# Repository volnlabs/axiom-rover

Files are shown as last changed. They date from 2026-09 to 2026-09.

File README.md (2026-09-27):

# Axiom Rover

**Interactive 3D inspection:** [open the hosted viewer](https://axiom-rover.vercel.app/) or [inspect the PCB](https://axiom-rover.vercel.app/?mode=pcb) — rotate, zoom, inspect all sides, hide the shell, or separate parts. [Local viewing and deployment instructions](viewer/README.md).

After cloning, use [the Git LFS checkout instructions](docs/build.md) to download the full assembly STEP, Pi reference STEP and viewer mesh before opening or rebuilding them.

A reusable 2WD release-test robot: one fixed Shrike/RP2040 + ForgeFPGA actuator base, a removable compute tray, an independent motor-power stop, and a wheels-raised stand. This is an **independent hardware repository**, not part of the AxiomOS source tree.

**Revision B is a design-review prototype, not released for fabrication or powered motion.** The carrier now has a bottom Pi 5 socket, two top Shrike R0.4 sockets, an onboard DRV8833 motor driver, and HC-SR04, wheel-encoder and IMU connectors. Vendor CAD and nominal socket models establish design coordinates; physical fit and powered tests remain outstanding.

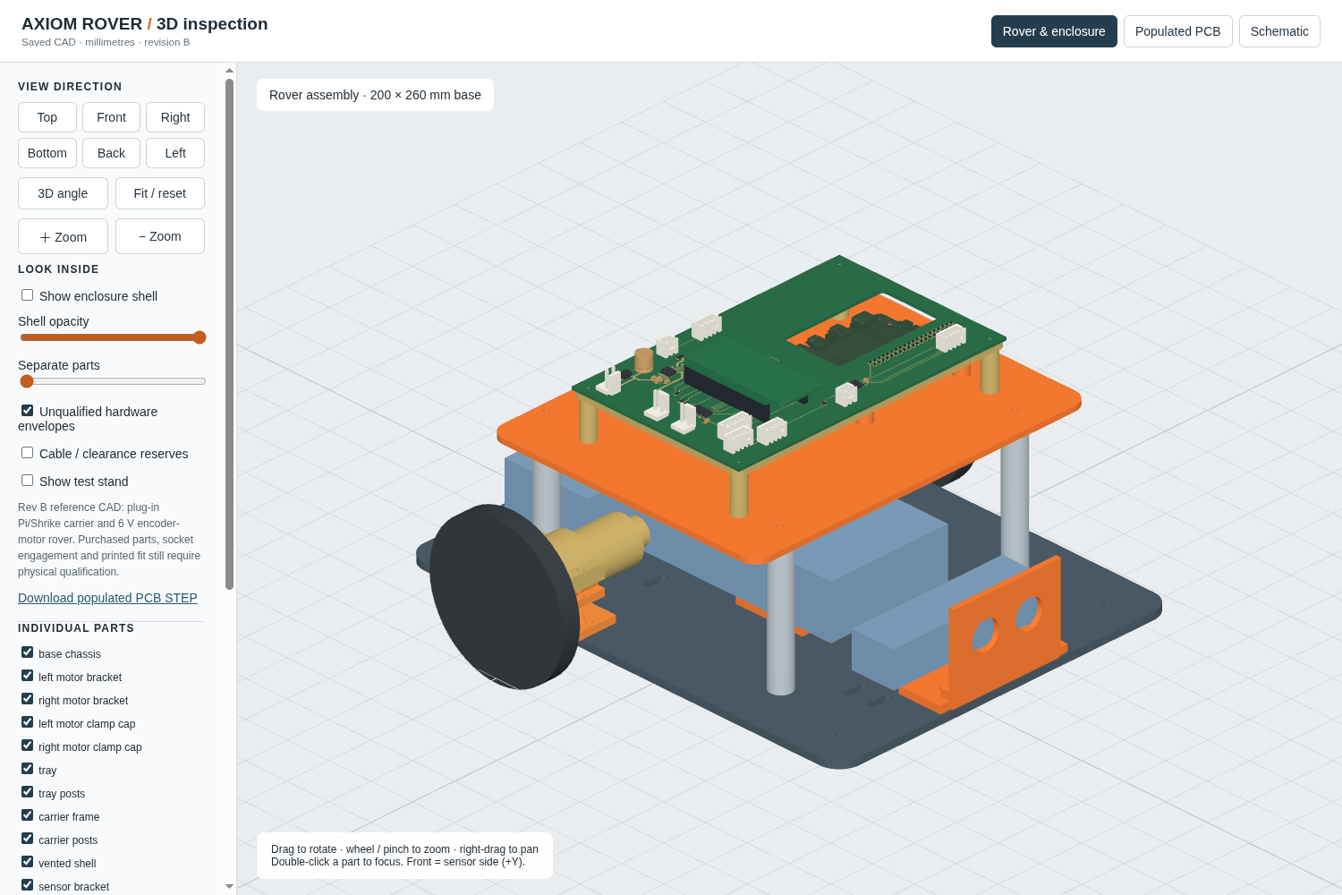
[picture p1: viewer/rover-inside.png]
Populated carrier and enclosure interior


- [Editable KiCad project](electronics/carrier.kicad_pro), [schematic](electronics/carrier.kicad_sch), [routed PCB](electronics/carrier.kicad_pcb), and [schematic drawing](electronics/out/schematic/carrier.svg).
- [Parametric mechanical source](mechanical/axiom_rover.py), [STEP assembly](mechanical/out/axiom_rover_assembly.step), and individual STL parts in [mechanical/out](mechanical/out/).
- [Electrical and harness contract](docs/electrical-contract.md), [wiring diagram](docs/harness.svg), [mechanical interfaces](docs/mechanical.md), [system BOM](bom/system-bom.csv).
- [Assembly, procurement and commissioning](docs/commissioning.md), [post-v1.0 compute roadmap](docs/compute-roadmap.md), [reproduction instructions](docs/build.md).
- [Controller bench fixture and motor-disconnected test procedure](docs/bench.md).
- [Native electrical check results](electronics/out/drc.json), [mechanical checks](mechanical/out/mechanical_checks.json), [populated assembly checks](mechanical/out/assembly-fit.json), [42 browser checks](viewer/browser-check.json), and [release gates](release-gates.json).

The carrier is 160 × 100 × 1.6 mm, two layers, with a cooler aperture. The Pi sits below it at a 16.5 mm gap and Shrike plugs into two 19-position sockets above. Two 6 V ThinkRobotics MOT3001-6V60RPM encoder motors drive 80 mm Pololu 3690 wheels. DRV8833 current regulation targets 1 A per channel; actual current and thermal behavior require bench measurements. The external fuse, normally-open motor-power relay, regulated motor source and separate host/base supplies remain off-board. Power down before compute swaps; J1 and alternate-host J12 cannot be used together.

A robot supplies repeatable evidence for named releases and fault cases. It cannot prove AxiomOS correct under every possible condition. Every physical result must identify the software/FPGA hashes, hardware revision, power state and raw capture.

Budget cap: ₹30,000 excluding compute boards and instruments, with ₹6,000 reserved for a revision. The current estimate is ₹20,821.98–₹45,459.98 before reserve (₹26,821.98–₹51,459.98 including it), not a vendor quote. First-order quotes must total at most ₹24,000 before ordering. Nothing has been purchased, fabricated, flashed or physically tested here.

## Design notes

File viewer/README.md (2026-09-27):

# Interactive Rev B.1 CAD inspection

Hosted on Vercel: [rover and enclosure](https://axiom-rover.vercel.app/),
[PCB](https://axiom-rover.vercel.app/?mode=pcb),
[schematic](https://axiom-rover.vercel.app/?mode=schematic).

Start `python3 -m http.server 8765 --bind 127.0.0.1` in the repository root.
Open [the rover](http://127.0.0.1:8765/viewer/) or
[the PCB](http://127.0.0.1:8765/viewer/?mode=pcb).

Drag to rotate, wheel/pinch to zoom, right-drag to pan, or select any of six
sides. Double-click a component to focus it. Hide or fade the enclosure,
separate the assembly, or hide individual components. Copper and schematic
views support zoom and pan. The same viewer works locally and as a static Vercel deployment.

The 160×100 mm Rev B.1 PCB includes a bottom Pi socket, two top Shrike sockets,
onboard DRV8833 and the sensor/encoder/IMU connectors. Geometry comes from
the actual saved PCB and STEP assemblies. Component meshes are grouped by
reference designator, including the individual socket contacts.

The Pi uses official source CAD. The Shrike model derives its outline and
hole positions from the R0.4 PCB; its male header plastic/pins are nominal,
and its component population is not fully modeled. The original Shrike STEP
has a documented header-position mismatch and is excluded from the assembly.
Samtec socket bodies and JST VH plastic are nominal drawing-based models;
other packages use KiCad library references. Motors/wheels use supplier
dimensions. Packs, caster and fit tolerances remain unmeasured envelopes.
This is a review assembly, not a physical fit or fabrication release.

Use [docs/build.md](../docs/build.md) to regenerate CAD, attach local models,
export populated STEP and refresh `meshes.json`. Provenance is in
`model-sources.json` and `../reference/`; hashes reject stale geometry.

[The browser self-test](http://127.0.0.1:8765/viewer/?test=1) checks required
components, the plugged module, every viewing direction, zoom, enclosure
visibility, exploded view, component hiding and schematic switching.
WebGL2 is required.

Three.js 0.180.0 / OrbitControls are vendored under MIT (`vendor/LICENSE`).
KiCad models retain their library license; see [THIRD_PARTY.md](../THIRD_PARTY.md).

## Vercel hosting

From the repository root, build and check the upload bundle:

```sh
python3 tools/build-viewer-site.py
python3 tools/check-viewer-site.py
node tools/check-viewer-ui.mjs
python3 tools/check-viewer.py --site-root .vercel/output/static --report-dir .cache/viewer-site-check
npx --yes vercel@59.15.0 link --yes --project axiom-rover --scope utkarshs-projects-88519d03
npx --yes vercel@59.15.0 deploy --prebuilt --prod --yes
```

The builder emits Vercel's [static Build Output API](https://vercel.com/docs/build-output-api)
under ignored `.vercel/output/`. Its fixed allowlist contains the viewer and project
pages, the CAD and circuit downloads linked from them, provenance, and licenses.
It rejects missing files and Git LFS pointers before replacing the output; run
`git lfs pull` if the geometry is still a pointer. Only files listed in the
builder reach the public site. `.vercel/project.json` is local account/project
configuration and stays ignored. Deploy the prebuilt output; a source deployment
from the repository root would upload unrelated CAD.

The output configuration serves `/viewer/` explicitly and applies a same-origin
content policy, basic security headers, and revalidation caching. Revalidation
matters because the asset URLs do not contain content hashes. The inline import
map is allowed by a hash generated from the source HTML during packaging.
The UI check uses Node.js 22+ and `chromium` on `PATH`; it runs against the
packaged site and writes browser reports under `.cache/viewer-ui/`.

The geometry is compressed losslessly from about 100 MB to 17 MB; the complete
bundle is about 40 MB. The hosted entry point uses the browser's native
[DecompressionStream](https://developer.mozilla.org/en-US/docs/Web/API/DecompressionStream).
A current browser with WebGL2 is required. Local viewing still loads the original
`meshes.json`. Both `/` and `/viewer/` support the existing `?mode=pcb`,
`?mode=schematic`, `?view=bottom`, and `?shell=0` links.

After deploying, check the public URL with the same browser test:

```sh
python3 tools/check-viewer.py --site-root .vercel/output/static \
  --report-dir .cache/vercel-live-check --url 'https://axiom-rover.vercel.app/'
```

The source hashes in that report describe the local bundle; verify downloaded
asset hashes separately when tying a remote deployment to this checkout. Hosting
does not change fabrication or physical-test release status.

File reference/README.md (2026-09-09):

# Vendor reference files

Retrieved 2026-09-09. These are vendor design/reference data, not measurements of the user's hardware. Source hashes are in `sources.json`.

- `shrike-r04/Shrike-lite.kicad_pcb` and `Shrike-lite.step`: unmodified Vicharak files from commit `763d0a7dd9ebdfc3f61de148457d5c34f112f61e`, `hardware/shrike-lite/kicad/v1_r0.4`. Hardware license: included `shrike-r04/LICENSE_HW.md` (CERN OHL v1.2).
- `raspberry-pi-5/*.pdf`: unmodified Raspberry Pi Ltd mechanical drawings, with their original reference-only notes. These have not been re-licensed by this project.

The Shrike R0.4 PCB outline is approximately **25.4×58.5 mm**, corner radius 2 mm. Board-coordinate bounds are approximately X=135.801105…161.201095, Y=75.7536…134.2536 mm. Socket rows J2/J4 have **19 positions each**, **2.54 mm pitch**, and **22.86 mm row separation**. J2 pin 1 is at (137.071095,86.8494); J4 pin 1 at (159.931095,86.8746). Pin numbers increase toward increasing PCB Y. The published rows have a small **0.0252 mm longitudinal offset**; retain source coordinates and assess connector tolerance instead of silently assuming perfect alignment. USB-C is at the low-Y end. Header drill size on the vendor board is 0.9 mm; the carrier socket drill must follow the selected socket's drawing, not copy the module's drill blindly.

The Pi board is 85×56 mm. With the official drawing's lower-left outline as datum, its M2.5 mounting hole centres are (3.5,3.5), (61.5,3.5), (3.5,52.5), (61.5,52.5), with Ø2.7 holes. The hole grid centre is 10 mm left of the board centre. The Rev B model uses board centre (-37.5,2), with hole X positions -76.5/-18.5 and Y positions +26.5/-22.5 mm.

No source dimensions establish socket engagement, soldered header orientation, actual board revision or enclosure fit by themselves.

The Pi STEP archive RP-010083-CA and its extracted STEP retain Raspberry Pi's
included license. The GPIO and Samtec stack datums are recorded in
[connector-sources.md](raspberry-pi-5/connector-sources.md).

The original Shrike STEP header locations differ from the R0.4 PCB by about
9.46 mm longitudinally after matching the board outline and USB orientation.
It is retained as discrepant vendor reference data. The review assembly uses
PCB-derived Shrike geometry instead; it must not imply that the original STEP
proves socket mating. Header plastic/pin lengths remain nominal until measured.

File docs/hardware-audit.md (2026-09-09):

> Historical findings for Rev A at commit 57851dc. Rev B replaces the harness-only PCB with physical Pi/Shrike sockets and onboard motor drive; see [the implementation ledger](revb-plan.md) and current CAD. This document preserves the earlier audit, not the current interface.

# Historical Rev A hardware audit — 9 September 2026

**Revision A does not implement the requested plug-in Shrike carrier. Do not order it as the complete robot PCB.** It is a routed, low-current harness adapter. Fabrication, physical fit and powered-motion release gates remain false. No hardware was connected or tested in this audit.

## Findings and disposition

| Interface | Finding | Disposition |
|---|---|---|
| Shrike mounting | No socket footprint; J2 is a 16-pin IDC harness connector. The suggested interposer has no PCB design. | Replace this interface with two female 1×19 sockets on the fixed carrier. |
| Shrike geometry | Official R0.4 PCB and STEP files exist but were not used in the initial assembly. | Saved under `reference/shrike-r04`; derive the socket and module model from these files. |
| Pi 5 mounting | The 58×49 grid spacing was correct, but its position relative to the 85×56 board envelope was wrong by 10 mm in X. | Corrected the tray holes/bosses to the official drawing datum; regenerated CAD and viewer meshes. This is a CAD correction, not a physical fit test. |
| Pi 5 electrical | Carrier J1 had generic UART names without Pi physical pin numbers. There is no Pi 40-pin socket or top-board design. | Added the explicit four-wire mapping to the electrical contract. Runtime UART routing remains to be demonstrated. |
| HC-SR04 | Carrier J3 order differs from the sensor header; the bracket lacks a measured board-retention interface, and the assembly omits the sensor body. | Added the required harness permutation. Exact sensor fit and trigger acceptance remain unverified. |
| L298N | An unspecified module is represented together with Shrike by one 60×35×15 box. That is not evidence that either module, connectors or heatsink fit. | Use separate models and retention for the actual L298N and Shrike. Check module jumpers and terminal order. |
| Motors, wheels, caster, batteries, switch, relay, fasteners | Exact SKUs, mating features, cable paths and installation access are incomplete or unmeasured. | Do not treat collision-free boxes as a complete enclosure assembly. Select/measure parts and qualify retention and clearances. |
| Runtime and motor power | Shrike firmware explicitly remains safe-low/non-operational; FPGA timing/runtime integration and motor-current qualification are missing. | No claim of a working or safe moving rover. Follow commissioning gates before motion. |

The artifact checker passed on the original design despite the Pi datum error. It checked consistency of the modeled geometry, not correspondence with the real Pi. The corrected generator now checks bores and surrounding spacer material at coordinates independently taken from the vendor drawing.

Verification after correction: the CadQuery generator and artifact checker passed, with zero unexpected intersections among the modeled shapes. Reintroducing the old centred grid in memory failed the drawing-coordinate bore check (15.928 mm³ of obstructing material). The refreshed viewer matched both STEP source hashes and passed its 22 browser checks. These are file/CAD/browser checks; no physical test was run.

## Source-based electrical checks

Rechecked the official R0.4 **PCB pad net names**, not only our own schematic. The contract's used Shrike connections match: J2-2 = 3.3 V; J2-3 = GPIO5; J2-4…7 = GPIO6…9; J2-8 = GND; J2-9/10 = GPIO10/11; J2-16…18 = F_GPIO0…2; J4-17/18 = GPIO17/16. These match the intended UART, sensor, motor-direction and FPGA-enable nets. This does not verify the user's installed board revision, header soldering, FPGA pad binding or running firmware.

Rechecked TI's package-specific tables: ISO7721DR pins 1…8 are VCC1, OUTA, INB, GND1, GND2, OUTB, INA, VCC2; SN74LVC1G17DBVR pins 1…5 are NC, A, GND, Y, VCC. The carrier assignments agree. Neither result proves assembled orientation, power sequencing, isolation performance or sensor-clone compatibility. [ISO7721, figure 5-4/table 5-1](https://www.ti.com/lit/ds/symlink/iso7721.pdf); [SN74LVC1G17, pin table](https://www.ti.com/lit/ds/symlink/sn74lvc1g17.pdf).

## Corrected architecture recommendation

Keep a **physical Shrike socket on the fixed actuator carrier**, with the Pi on its removable upper tray. Use two female 1×19 socket strips, a board-outline/pin-1 marking, and a mechanical guide/retainer that prevents reversed or offset insertion. Select the actual socket/header pair and engagement height before finalizing its footprint. Preserve access to Shrike USB-C, boot/reset and debug connections. Keep the host/base power boundary and independent motor-power stop.

A Shrike socket on a **Pi 5 top add-on board** is also feasible, but it couples the actuator controller mechanically to the computer being swapped. It requires its own 40-pin mating connector, defined stack height, actual cooler/connector clearance and a new thermal/fit review. The official Active Cooler drawing gives 63.5×42.5×13.7 mm reference dimensions. A top board must allow fan intake/exhaust, plug access and installation space; the current enclosure proves none of those. Do not call it HAT/HAT+ compliant without checking the corresponding Raspberry Pi specification.

Before releasing either arrangement: import accurate separate board/component models; select all mating connectors and mounting hardware; check every pad against the vendor and every harness end against its device; rerun ERC/DRC, connectivity and actual-part mechanical checks; perform a paper/template socket fit and unpowered assembly; then follow current-limited electrical, partial-power, stop/watchdog and raised-wheel commissioning. Exact purchased dimensions and physical measurements remain required.

Sources: [pinned Vicharak R0.4 hardware](https://github.com/vicharak-in/shrike/tree/763d0a7dd9ebdfc3f61de148457d5c34f112f61e/hardware/shrike-lite/kicad/v1_r0.4), [Pi 5 mechanical drawing](https://datasheets.raspberrypi.com/rpi5/raspberry-pi-5-mechanical-drawing.pdf), [Active Cooler drawing](https://datasheets.raspberrypi.com/cooling/raspberry-pi-active-cooler-mechanical-drawing.pdf). Raspberry Pi labels its drawings approximate/reference-only and directs readers to physical hardware for complete component representation.

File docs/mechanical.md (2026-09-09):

# Axiom Rover mechanical Rev B

`mechanical/axiom_rover.py` is deterministic CadQuery 2.6 source. Run `/tmp/axiom-cad-tools/venv/bin/python mechanical/axiom_rover.py --output mechanical/out` to recreate the printable STLs, assembly STEP, `shrike-module.step`, overview and collision report.

The PETG lower deck is 200 × 260 × 4 mm. The 80 × 10 mm [Pololu 3690](https://www.pololu.com/product/3690) wheel references use the supplied 4 mm D collets and centres at `x=±120, y=-50, z=22.5`; the ground datum is `z=-17.5`. The four-pad test stand supports the base underside, clears both wheel references, and does not load motor axles. The shell wheel arches are enlarged for the 80 mm diameter and its upper rim reaches `z=141`. The native PCB-derived Shrike board top is about `z=121.324`; `z=135` remains the enclosure-clearance plane. The board-only export deliberately does not claim clearance for unmodeled Shrike components.

Each ThinkRobotics MOT3001-6V60RPM motor is a **vendor-dimension reference, not a measured fit**: 25 mm gearbox diameter × 23 mm long, 24.4 mm motor body × 31 mm, 9 mm encoder and 4 mm D shaft × 12 mm. The two split clamps use a 25.70 mm bore (0.35 mm radial print clearance), a 23.6 mm clamp length and a 1 mm split gap for closure. Each lower clamp foot is `24 × 52 mm` at the gearbox axis with two accessible M3 deck bolts at `y=axle±22`; it has two M3 clamp screws. The archived supplier drawing is [reference/motors/thinkrobotics25-dimensions.jpg](../reference/motors/thinkrobotics25-dimensions.jpg); validate purchased gearboxes, gearbox face/shaft position, print tolerance and clamp load before fabrication. The 80 mm wheels and their 4 mm collets are also vendor references; their published drawing specifies a 10.3 mm maximum width and about 6 mm collet/plate thickness, compatible with the 12 mm shaft on paper only.

The host pack reserve moved below the tray, centrally at `70 × 120 × 30 mm`, lower face `z=10`; it has four deck strap slots. The former front/rear motor-pack (`90 × 50 × 25`) and base-5V (`90 × 25 × 20`) reserves remain explicitly **unqualified**. Moving the host reserve exposed an encoder conflict at the previous wheel track; the 120 mm wheel centres give the encoder a 5 mm lateral clearance to that reserve. This has no physical-pack fit claim.

The Pi 5 drawing datum is PCB-local `(0,20)..(85,76)`, world centre `(-37.5,2)`, board bottom/top `z=89/90.6`. Its four drawing holes are world `(-76.5,26.5)`, `(-18.5,26.5)`, `(-76.5,-22.5)`, `(-18.5,-22.5)`. Power-off service is: unscrew and lift the carrier at least 7 mm to disengage GPIO; remove the carrier and perimeter frame; unbolt the Pi; lift it 2 mm; then slide it left through the `z=76..110` opening. `pi5_after_carrier_removal_service_SWEEP` is the conservative full official-Pi bounding volume for that final slide and is checked against the remaining printable parts. The official Pi STEP is included as a separate source-CAD reference. Its 85 × 56 × 1.276 substrate solid, not its full connector-inclusive bounds, is placed natively with source lower-left at world `(-80,-26)` and board lower face `z=89`; neither source CAD nor the Shrike CAD is mirrored.

The carrier uses the final 160 × 100 × 1.6 PCB contract: KiCad `(0,0)` is world `(-80,+50,z107.1)` and KiCad `+y` maps world `-y`. It is supported independently at PCB `(5,5)`, `(155,5)`, `(155,95)`, `(5,95)` by four dielectric posts down to the tray. Its frame is a 3 mm perimeter rim (`160 × 100` outside, `154 × 94` open inside) with 8 mm corner bosses and M3 holes, leaving the full PCB interior open for THT tails and the DRV thermal-pad back. The Pi drawing holes remain clearanced. The `60 × 34` **airflow window** at PCB `(8,32)..(68,66)` is therefore an airflow projection, not a component-through-fit claim: it clears the specified `60 × 34 × 13.7` projection only; the official cooler outline is `63.5 × 42.5`. The open interior also clears the downward Samtec ESQ-120-24-G-D reference body (`51.31 × 4.95 × 13.59`), placed from the official Pi header datum `pin1=(8.37,24.77)`, `pin2=(8.37,22.23)` in PCB-local coordinates. `carrier_tails_CLEARANCE_REFERENCE`, derived from J1–J13 drilled pads in `electronics/out/pad-geometry.json`, is checked clear of the rim and bosses. The Pi PCB-top-to-carrier-underside gap is 16.5 mm; the stated 5.63 mm electrical engagement remains an electronics/mechanical stack assumption, not a measured assembled result.

Shrike sockets are separate reference geometry: each SSW row is `48.77 × 2.41 × 8.51` above the carrier PCB, using the supplied row pin-1 coordinates `(100.27,21.0958)` and `(123.13,21.1210)`. Their top is `z=117.21`; the Shrike PCB lower face is modeled at `z=119.75`, with a nominal `2.54 × 48.26 × 2.54` male-header plastic section below it and 38 nominal `0.64` square, 6 mm pins below that. Plastic and pins are explicitly unmeasured. `shrike_pcbCAD_REFERENCE` imports the native KiCad board-only STEP export, including its actual outline, rounded corners and pads. `mechanical/out/shrike-module.step` combines that native board with the nominal plastic and all 38 pins, normalized to the J2 pin-1 contract origin with board lower face `z=0`; this is the model for KiCad/viewer attachment. The optional `shrike_component_UNMEASURED_ENVELOPE` covers the full bay from its board bottom through `+8 mm`; `shrike_usb_wire_UNMEASURED_ENVELOPE` reserves low PCB-Y/world `+Y` for a USB plug and wire. They are visible clearance references only and do not claim measured component fit. The vendor `Shrike-lite.step` remains report-only: a proper 180° Z rotation (never a mirror) can align its nominal `25.45 × 58.55008 × 1.51` substrate to the bay, but independent circular-hole extraction finds both source rows offset about `(+0.025,+9.462) mm` from the carrier contract. It is excluded from the assembly so it cannot imply a false mating fit.

`mechanical_checks.json` labels printable parts, vendor references, contract references and unqualified envelopes separately. It performs exact intersections for printable/reference geometry, allows wheel–shaft and intended Shrike pin–socket engagement, checks the airflow aperture and Pi service sweep, and records the vendor-STEP mismatch separately. Passing CAD checks do not validate print strength, motor fit, wheel retention, pack fit, thermal behavior, loading, speed, payload or physical tests.

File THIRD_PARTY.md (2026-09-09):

# Third-party design sources

`electronics/Rover.pretty/*.kicad_mod` are copies of the KiCad footprint library shipped with KiCad 10.0.6, except `Pi5_Socket_2x20` and `SSW-119-01-G-S`, which are original local footprints derived from the cited Samtec dimensions and Pi STEP datum. Original library families are recorded by `electronics/generate.py` and `electronics/out/assembly-bom.csv`; Standard-library pad shapes have not been redrawn; local model paths are updated. The upstream KiCad Libraries license is [CC BY-SA 4.0 with the KiCad design exception](electronics/Rover.pretty/LICENSE.md). Attribution: [KiCad Libraries contributors](https://gitlab.com/kicad/libraries/kicad-footprints). See the included license for the design exception and conditions on library redistribution.

Shrike pin assignments are derived from the pinned official Vicharak schematic; source URLs and SHA-256 values are in `docs/electrical-contract.md`. The pinned vendor PCB and STEP files are retained under `reference/`. U1/U2 assignments use Texas Instruments datasheets linked there. Raspberry Pi's mechanical drawing is linked in `docs/mechanical.md`. Their product names remain their owners' names; this is an independent reference prototype.

Unmodified official Shrike R0.4 PCB/STEP files and their CERN OHL v1.2 license, and unmodified Raspberry Pi Ltd reference mechanical PDFs, are retained in `reference/`. See its README and `sources.json` for provenance and hashes. The Raspberry Pi drawings retain their original notices and are not covered by the Shrike license.

KiCad, Freerouting and CadQuery are external tools, not project dependencies vendored into Git. The ignored `.cache/` directory may contain locally downloaded tooling. No repository-wide public license is chosen on the user's behalf; retain third-party attribution if the project is later published.

`electronics/models/` includes KiCad library package STEP references, attributed
in `viewer/model-sources.json`. Most carry CC BY-SA 4.0 with the KiCad design
exception. `D_SMB.step` and `CP_Radial_D8.0mm_P3.50mm.step` instead carry
GPLv3-or-later with the design exception embedded in their headers. Original
model notices and GPLv3 are retained in [viewer/model-licenses.txt](viewer/model-licenses.txt).
Samtec
socket bodies and the simplified JST VH body are original nominal geometry
created by `viewer/export_meshes.py` from cited manufacturer dimensions; they
are not manufacturer-certified STEP assemblies. The DRV8833 uses KiCad's
TSSOP-16-1EP 4.4×5 mm / EP3.4×5 mm reference model for the matching package
body; its exact PWP land pattern remains the separate PCB footprint.

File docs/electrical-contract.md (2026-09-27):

# Axiom rover electrical contract — Rev B.1 review

This is the accepted **160 x 100 mm Pi 5 carrier** contract. It records a design
under review, not a fabricated board, qualified harness, motion release, or
firmware implementation.

## Fixed boundaries

- Pi 5 is below the carrier. `J1` is `ESQ-120-24-G-D`, bottom-mounted, with a
  nominal carrier-underside-to-Pi-PCB gap of **16.5 mm**.
- Shrike R0.4 mates through `J2` and `J4`, each `SSW-119-01-G-S` 1 x 19
  socket. Delivered-header orientation and continuity remain physical checks.
- Shrike USB-C is its **only** 5 V input. Pi 5 V pins 2 and 4 and Shrike J2/J4 pin 1 (`VUSB`) are NC.
  `BASE_5V` is a separately supplied sensor rail only.
- The external 6 V motor rail reaches J7 only after an independent, rated stop
  relay and fuse. The PCB does not rate or replace either device.
- U1 isolates `H_GND` and `BASE_GND`; no carrier copper intentionally joins them.
- Rev B.1 retains the 160 x 100 mm outline, mounting holes, cooler aperture,
  connector positions and pinouts. Check the generated board against these
  fixed interfaces before fabrication.

## Pi socket and Shrike connector map

`J1` uses Pi physical-header numbering. All pins not listed are NC.

| J1 / Pi pin | Carrier net | Use |
|---:|---|---|
| 1, 17 | `HOST_3V3` | Pi 3.3 V for U1 host side |
| 6, 9, 14, 20, 25, 30, 34, 39 | `H_GND` | Pi ground for U1 host side |
| 8 | `H_TX` | Pi UART TX |
| 10 | `H_RX` | Pi UART RX |
| 2, 4 | NC | Pi 5 V; never power Shrike/carrier from Pi 5 V |

| J2 pin | Net | Shrike function / destination |
|---:|---|---|
| 1 | NC | — |
| 2 | `BASE_3V3` | Shrike 3.3 V |
| 3 | `ESTOP_RP` | RP GPIO5 observe |
| 4, 5 | `L_IN1`, `L_IN2` | left direction inputs |
| 6, 7 | `R_IN3`, `R_IN4` | right direction inputs |
| 8, 13 | `BASE_GND` | base return |
| 9, 10 | `US_TRIG`, `US_ECHO_3V` | HC-SR04 trigger / protected echo |
| 11, 12, 14, 15 | NC | — |
| 16 | `ESTOP_FPGA` | FPGA stop input |
| 17, 18 | `FPGA_PWM_L`, `FPGA_PWM_R` | FPGA PWM gates |
| 19 | `FAULT_FPGA_N` | FPGA `F_GPIO7` fault observe |

| J4 pin | Net | Shrike function / destination |
|---:|---|---|
| 1 | NC | — |
| 2 | `BASE_3V3` | Shrike 3.3 V |
| 3 | `IMU_INT` | IMU interrupt |
| 4 | `FAULT_RP_N` | RP GPIO28 fault observe |
| 5, 6 | `IMU_SCL`, `IMU_SDA` | I2C clock / data |
| 7, 13, 19 | `BASE_GND` | base return |
| 8, 9, 15, 16 | NC | — |
| 10, 11 | `ENC_R_B`, `ENC_R_A` | right encoder B / A |
| 12, 14 | `ENC_L_B`, `ENC_L_A` | left encoder B / A |
| 17, 18 | `RP_UART_RX`, `RP_UART_TX` | isolated UART RX / TX |

U5 (`SN74LVC125ADR`) gives each controller a separate one-way stop and fault
observation channel. Its four active-low enables are grounded; R16–R19 are
1 kΩ output resistors. J2-19/F_GPIO7 receives `FAULT_FPGA_N`; J4-4/GPIO28
receives `FAULT_RP_N`. Neither receiver can drive the source `DRV_FAULT_N`,
the hardwired `ESTOP_N`/nSLEEP net, or the other controller's observation
channel. Verify buffer propagation and the delivered Shrike pin labels.

## Carrier connectors and peripherals

| Ref | Family / purpose | Pin order, as generated |
|---|---|---|
| J3 | JST XH 1x4, HC-SR04 | `BASE_5V`, `SENSOR_TRIG`, `US_ECHO_5V`, `BASE_GND` |
| J5 | JST XH 1x2, logic NC stop loop | `BASE_3V3`, `ESTOP_N` |
| J6 | JST XH 1x2, sensor 5 V input | `BASE_5V`, `BASE_GND` |
| J7 | JST VH B2P-VH, post-fuse/stop 6 V | `MOTOR_6V`, `BASE_GND` |
| J8 | JST VH B2P-VH, left motor | `MOTOR_L_P`, `MOTOR_L_N` |
| J9 | JST VH B2P-VH, right motor | `MOTOR_R_P`, `MOTOR_R_N` |
| J10 | JST XH 1x4, left encoder | `BASE_GND`, `BASE_3V3`, `ENC_L_A`, `ENC_L_B` |
| J11 | JST XH 1x4, right encoder | `BASE_GND`, `BASE_3V3`, `ENC_R_A`, `ENC_R_B` |
| J12 | JST XH 1x4, alternate host UART | `HOST_3V3`, `H_GND`, `H_TX`, `H_RX` |
| J13 | JST XH 1x5, IMU | `BASE_GND`, `BASE_3V3`, `IMU_SDA`, `IMU_SCL`, `IMU_INT` |

The HC-SR04 uses 5 V. R1 (1 kΩ), R2 (2.2 kΩ), R3 (3.3 kΩ), and U2
`SN74LVC1G17DBVR` drive and protect its 3.3 V interface. R14/R15 are 4.7 kΩ
I2C pull-ups. Actual HC-SR04 header order and trigger threshold need bench
verification.

Encoder connector order is fixed above, but actual motor wire-end order,
polarity, phase, and quadrature CPR are unknown. Establish them by continuity
and a low-energy direction/phase test.

## Motor drive and stop behavior

U3 is `DRV8833PWPR`. R7/R8 are Stackpole `CSRT1206FTR200`, 0.20 Ω, 1 %, 1 W current-sense parts. The
design intent is **1 A nominal per motor channel**, contingent on current,
thermal, supply-sag, and driver-fault measurements.
For Rev B.1, place R7/R8 beside U3 with each sense trace at most 7 mm;
limit U3-to-capacitor pad-centre routed lengths to 4 mm for VM/VINT and
3 mm for VCP.
Retain 12 exposed-pad thermal vias, ground isolation and 0.8 mm motor trunks.
These are layout targets to verify in the regenerated board, not measured
electrical or thermal performance.

| Direction source | PWM gate | DRV8833 input |
|---|---|---|
| `L_IN1` | `FPGA_PWM_L` | `DRV_AIN1` |
| `L_IN2` | `FPGA_PWM_L` | `DRV_AIN2` |
| `R_IN3` | `FPGA_PWM_R` | `DRV_BIN1` |
| `R_IN4` | `FPGA_PWM_R` | `DRV_BIN2` |

U4 (`SN74LVC08ADR`) performs these AND gates. PWM low takes both inputs of a
bridge low for a coast stop. `nSLEEP` is the `ESTOP_N` stop level and is
**not** PWM. R4 pulls the stop net low; R5/R6 pull PWM gates low; R10-R13 pull
direction inputs low; R9 pulls open-drain `DRV_FAULT_N` to `BASE_3V3`.

```text
logic: J5-1 BASE_3V3 -> S1A NC -> J5-2 ESTOP_N (R4 pulls to ground)
coil:  fused regulated 6 V -> S1B NC -> K1 rated coil -> BASE_GND
power: fused regulated 6 V -> K1 COM / normally-open contact -> J7-1
return: motor source negative -> J7-2 BASE_GND
K1 coil: correctly polarized rated flyback clamp; measure release time.
```

Select relay, fuse, wire, connector contacts, and source from measured stall
current and rated DC-inductive service. This contract makes no rating, trip,
or release-time claim.

## Selected motors and wheels

Use two ThinkRobotics **MOT3001-6V60RPM** 6 V, 60 RPM encoder motors, 25 mm
diameter. Supplier information states 103:1 gearing and 46 RPM loaded. It does
not establish delivered wire order, quadrature CPR or thermal performance. The seller lists 1.8 A stall current; this is a sourcing datum, not a measured limit of our assembly. Use
Pololu **3690**, an 80 x 10 mm wheel pair with 4 mm D-bore collets; fit and
retention remain mechanical qualification items.

## Release state

Physical tests, fabrication, and motion release are **false / not run**. This
repository does not claim implemented, flashed, or validated Pi, RP2040, or
FPGA motor-control firmware.

## Service points and assembly

Rev B.1 has ten 1.5 mm top-side probe pads, three top fiducials,
low-current through-hole ground thermal relief, and connector pin labels.
Reflow surface-mount parts before fitting the through-hole connectors.

| Pad | Net |
|---|---|
| TP1 | `HOST_3V3` |
| TP2 | `H_GND` |
| TP3 | `BASE_3V3` |
| TP4 | `BASE_5V` |
| TP5 | `MOTOR_6V` |
| TP6 | `BASE_GND` |
| TP7 | `ESTOP_N` |
| TP8 | `DRV_FAULT_N` |
| TP9 | `SENSE_L` |
| TP10 | `SENSE_R` |

Verify access and isolation on the actual assembly before probing. Instrument
ground leads must not bridge `H_GND` and `BASE_GND`; use isolated or differential
measurement for simultaneous observations across the UART isolation boundary.

## Host transport and electrical limits

Pi pins 8/10 are GPIO14/15 and require the intended RP1 UART pin mux and driver.
Pi 5's primary debug UART is a separate three-pin header; a successful Linux
UART setup does not prove AxiomOS support. Disable boot/console traffic on the
control channel. Use the existing AxiomOS wire protocol; no new protocol or
runtime is implemented here. J12 is an alternative host entry: electrically
remove the Pi from J1 before using it, including Pi 3.3 V. Never connect two
TX outputs or two host 3.3 V sources together.

J13 supplies 3.3 V only. Use a documented 3.3 V-compatible IMU breakout and
check its pull-ups; parallel pull-ups may require omitting R14/R15. Encoder
ports also supply 3.3 V only; verify output type and noise margin before wiring.
HC-SR04 echo passes a 2.2 kΩ / 3.3 kΩ divider (nominal 3.0 V at 5.0 V) and
an SN74LVC1G17 buffer with partial-power isolation. The 1 kΩ trigger resistor
limits current; it does not raise the 3.3 V trigger level.

D1 SMBJ6.0A is a transient clamp, not a regulator, regeneration sink or
reverse-polarity controller. C8 is polarized. Use keyed, polarity-checked
6 V input with a suitably rated external fuse. Test VM overshoot and rail decay
at stop/reverse; TVS pulse ratings alone do not qualify motor regeneration.
Exact manufacturer sourcing for generic D1 SMBJ6.0A and C8 470 µF, 16 V
remains unresolved; confirm orderable parts and footprints before fabrication.
U3 uses the PWP exposed-pad package, not the lower-current PW package.
The 0.30 mm driver breakout necks feed 0.8 mm motor trunks and 1.2/0.6 mm
vias; two-layer copper and thermal-via performance remain physical test gates.
This carrier does not claim formal Raspberry Pi HAT+ compliance: ID pins are NC.

Sources: [Stackpole CSRT](https://seielect.com/catalog/SEI-CSRT.pdf),
[TI DRV8833](https://www.ti.com/lit/ds/symlink/drv8833.pdf),
[TI SN74LVC125A](https://www.ti.com/lit/ds/symlink/sn74lvc125a.pdf),
[TI SN74LVC08A](https://www.ti.com/product/SN74LVC08A),
[TI ISO7721](https://www.ti.com/product/ISO7721),
[TI SN74LVC1G17](https://www.ti.com/product/SN74LVC1G17),
[JST VH](https://www.jst-mfg.com/product/pdf/eng/eVH.pdf),
[ThinkRobotics motor](https://thinkrobotics.com/products/25mm-encoder-dc-metal-gearmotors),
[Pololu wheels](https://www.pololu.com/product/3690), and the pinned
[Pi/Samtec reference notes](../reference/raspberry-pi-5/connector-sources.md).

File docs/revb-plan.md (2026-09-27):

# Rev B implementation and evidence ledger

Accepted design: independent 6 V, <=2 kg indoor rover; ThinkRobotics
MOT3001-6V60RPM encoder motors, Pololu 3690 80 mm wheels, onboard
DRV8833PWP with nominal 1 A/channel current regulation, Pi 5 top carrier,
physical Shrike R0.4 sockets, HC-SR04, two encoders and external I2C IMU.
All work stays in this repository. No AxiomOS firmware is changed or flashed.

- [x] Replace electrical carrier, route and run native KiCad ERC/DRC/parity.
- [x] Replace mechanical mounts, integrate controller/socket geometry and inspect clearances.
- [x] Regenerate populated board, assembly, six-sided interactive viewer and drawings.
- [x] Update BOM, harness contract, commissioning and source provenance.
- [x] Independent review and reproducible artifact/browser checks.

Ruling: use a 160 x 100 mm carrier with a cooler aperture and an outboard
Shrike bay. The former 120 x 80 mm harness board did not allocate space for
both mating boards, cooling and motor-current copper. Move the host power
pack below the compute tray. Cost if fit is wrong: revise the carrier/tray
before fabrication; physical dry-fit remains required.

Baseline: commit 57851dc, clean checkout; tools/check-artifacts.py passed.
Branch: hardware/shrike-pi5-revb. Work remains in the user-selected checkout
so existing local viewer URLs and CAD tool cache remain valid.

Physical tests, vendor quotes and orders are not available from CAD work.
Fabrication and motion release stay false until evidence is attached.

Electrical evidence: native KiCad 10.0.6 ERC/DRC/parity reports are clean.
A separate scratch regeneration from `electronics/generate.py` and the saved
router session also produced zero DRC, connectivity and parity findings.
The saved importer includes the local VM connection; unused vias are removed
only by UUIDs in the fresh DRC report.

Final review evidence: `mechanical/out/mechanical_checks.json` and
`mechanical/out/assembly-fit.json` pass with no unexpected intersections.
`viewer/browser-check.json` records 34 passing checks, including every side,
zoom, part hiding and correct stack order in the exploded view.
`tools/check-artifacts.py` passes source/artifact freshness, connector maps,
reference hashes and BOM arithmetic. Independent electrical review and the
parent mechanical review were incorporated; physical release gates remain false.

## Rev B.1 reliability and serviceability review

This is the follow-on layout review; the Rev B evidence above is historical.
Keep the 160 x 100 mm outline, mounting holes, cooler aperture, every connector
position and pinout, 0.20 Ω sense resistors, 12 U3 thermal vias, isolated host
and base grounds, and 0.8 mm motor trunks. Move R7/R8 beside U3 so each sense
trace is at most 7 mm; limit U3-to-capacitor pad-centre routed lengths to
4 mm for VM/VINT and 3 mm for VCP. Add ten top-accessible electrical test pads listed in
[the contract](electrical-contract.md), three top fiducials, low-current
through-hole ground thermal relief and connector pin labels. Reflow SMD before
hand-soldering through-hole parts.

- [x] Regenerate B.1 CAD/artifacts; check placement, routing, ERC/DRC and parity.
- [x] Review assembly access, drawings, viewer and connector labels in CAD.
- [ ] Source exact manufacturer/order codes for generic D1 SMBJ6.0A and C8
      470 µF, 16 V; verify footprints and availability.
- [ ] Record physical fit, partial-power/backfeed, regeneration, thermal,
      stop-path and current-chopping evidence under [commissioning](commissioning.md).

The Rev B.1 review does not release fabrication or powered motion. Physical
evidence and all release-gate values remain pending.

Recorded B.1 CAD evidence (2026-09-27): KiCad 10.0.6 reports zero ERC, DRC,
unconnected-item and schematic-parity findings. A separate scratch regeneration
from the generator and saved session also passes. The saved session includes
the TP5 probe branch; the generator retains the locked driver routes.

| Top-copper pad-centre route | Length | Target |
|---|---:|---:|
| U3–R7, SENSE_L | 5.385 mm | ≤7 mm |
| U3–R8, SENSE_R | 5.385 mm | ≤7 mm |
| U3–C5, VM | 2.462 mm | ≤4 mm |
| U3–C7, VINT | 3.494 mm | ≤4 mm |
| U3–C6, VCP | 2.997 mm | ≤3 mm |

The independent regression freezes all 13 Rev B connector pin maps and checks
placement, outline/cooler arcs, 12 thermal vias, ten probe pads, ground separation,
fiducials, reliefs and route lengths. Injected connector swaps and cut sense
routes are rejected. The populated STEP has no unexpected frame, post or shell
intersections. Viewer checks pass 42/42, UI checks 77/77, and the static bundle's
links, routes, headers and LFS preflight pass. The procurement BOM still has
47 fitted parts; the probe pads and fiducials need no purchased components.

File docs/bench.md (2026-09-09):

# Rev B controller bench

This fixture belongs to the rover repository. AxiomOS remains the owner of the
host, RP2040 firmware and FPGA implementation; this work does not edit, replace
or flash them. The first milestone is **motor power disconnected**, with measured
logic behavior. Generated traffic and synthetic traces are software test inputs,
not measurements of a Pi, Shrike or motor.

## Control contract

Use the existing isolated Pi UART to RP2040 and Shrike's existing internal
RP2040-to-FPGA bus. RP2040 is the sole command authority for Rev B. The FPGA
generates the two PWM gates and expires commands using its local clock. Runtime
SPI on the internal configuration wires requires explicit ownership after FPGA
configuration; merely loading a bitstream does not implement a runtime interface.

Direction and PWM must refer to the same accepted command. For each update that
changes direction: mask PWM, obtain confirmation that it is disabled, change
direction, observe the specified settling interval, and only then enable the
matching unexpired command. Stop, fault, expiry or reset cancels an in-progress
update. An old acknowledgement must never enable a newer command. RP2040 must
not keep renewing a motion lease after host commands expire.

Startup, unconfigured FPGA, expired commands and controller resets must leave
the gates low. Emergency stop and driver fault latch a stopped state; releasing
the input does not authorize motion. Require explicit rearm and a fresh command.
After hardware nSLEEP rises, allow at least the DRV8833's specified 1 ms wake-up
time before enabling PWM. Reject incomplete, malformed, repeated and reordered
commands without extending an existing lease.

The FPGA watchdog cannot detect loss of its own clock. The independent physical
stop still removes motor power. Automatic protection against a frozen FPGA would
require an independently clocked watchdog or equivalent hardware; Rev B does not
claim that coverage. Direct Pi-to-FPGA SPI is deferred until the existing path is
measured and a separate carrier revision is justified.

### Interface baseline and handoff to AxiomOS

The inspected committed interface is AxiomOS
`4f5aa9037832b9ee27145c5ffc87f4c3ca707e18`. Wire compatibility is checked against
that immutable snapshot, not the concurrently edited AxiomOS working tree.
UART is 115200 8N1, with `7e 01 TYPE LEN PAYLOAD CRC_LE` and CRC16-CCITT/FALSE
over version through payload. The existing protocol has no separate ARM opcode:
soft-stop release followed by a strictly newer setpoint is its rearm sequence.

There are runtime prerequisites that a matching packet format does not resolve:

- The current RP2040 entry point intentionally remains safe-low without a
  validated bitstream/timing manifest and atomic adapter.
- The current generic link watchdog refreshes liveness on heartbeats; this can
  retain the last setpoint. The completed control path must demonstrate bounded
  command authority when heartbeats continue but fresh motor intent stops.
- The current SPI READY/COMMAND_VALID status does not itself prove that PWM was
  masked before an RP direction update. The completed adapter/FPGA must expose
  and honor that confirmation, or supply an equivalent measured interlock.
- Runtime reset, driver-fault recovery and rearm semantics must be verified
  end-to-end. The fixture does not add a new protocol or emulate missing firmware.

These are acceptance requirements for the separately completed AxiomOS work,
not changes made by this repository. A physical run must identify the actual
flashed artifacts, even when they are newer than this wire snapshot.

## Before capturing

Copy [the case template](../bench/case-template.json) for each acquisition. Its
null fields deliberately fail validation: fill them with the actual identities
and predeclared timing limits. `event_us`, `stop_deadline_us` and
`observe_until_us` are **absolute timestamps on the capture's microsecond axis**;
the permitted stop latency is `stop_deadline_us - event_us`. Extend the hold
window through stop/fault release to check that releasing it does not restart.
Set each case's `max_pre_event_drive_gap_us` from the validated PWM period and
acquisition margin. The checker requires a recent drive-high observation within
that distance before the stimulus, with the corresponding direction still active
immediately before it. This allows a normal PWM low phase while rejecting drive
activity that ended well before the test event.
For a startup-only acquisition, use `off_intervals: []`; the report then checks
startup without claiming any active-stop case passed. Choose a positive startup
observation window that covers the controller's specified boot behavior.

For physical traces the checker reserves
`2 * max(time_resolution_us + timing_uncertainty_us)` across the listed
instruments. Measured mask/settling and wake-up intervals must exceed their limits
by that margin, stopping must occur that much before the deadline, and the capture
must extend that much beyond the hold window. `max_sample_gap_us` is the largest
permitted gap between recorded samples; choose it from the shortest event that
must be resolved. A declared gap allowance is not proof that no pulse was missed.

Follow [commissioning](commissioning.md) for unpowered continuity, delivered-board
pin verification, independent supplies and partial-power checks. Leave the motor
6 V input physically disconnected for this phase. No connected Shrike/serial
adapter was visible during fixture preparation on 2026-09-10; physical cases are
NOT RUN.

Record carrier and Shrike revision, Pi model, software commits, flashed binary
and bitstream SHA-256, timing manifest, power conditions, instrument model and
firmware, probe threshold, sample interval, timing uncertainty and calibration.
Set acceptance bounds from the controller timing manifest and component limits
**before** acquiring a trace. Preserve raw instrument exports alongside any
normalized CSV; retain the conversion command and channel mapping.

Probe the base side of the isolator with a base-referenced logic analyzer. Do not
bridge host and base grounds with analyzer leads or a shared, non-isolated USB
ground. A typical eight-channel analyzer cannot simultaneously record all signals
used by the full checker; use sufficient channels or a qualified synchronized
capture arrangement. Separate unsynchronized acquisitions do not prove ordering.

## Physical cases

| Case | Stimulus and required observation |
|---|---|
| Startup | Power/reset with no valid command: PWM and gated driver inputs remain low. |
| Command path | A fresh authorized command reaches the intended direction and PWM; retain UART and internal-bus captures as well as output traces. |
| Reverse | Both directions tested per wheel; PWM is confirmed low before direction changes and stays masked for the declared interval. |
| Expiry / UART loss | Establish active output, then stop valid host traffic; gates fall within the declared bound and remain off. |
| Intent loss with live link | Establish active output, then continue heartbeats but stop fresh motor intent; the declared command-authority bound still expires. |
| Invalid traffic | While active, inject a bad checksum, incomplete frame, duplicate and reordered command; none extends the valid command's expiry. |
| Controller resets | Reset RP2040 and FPGA separately from active output; stop within the declared bound, with no automatic restart. |
| Emergency stop | Open and break the NC loop; nSLEEP follows the physical stop and PWM/output gates become low within their bounds. Releasing the loop leaves motion disarmed. |
| Driver fault | Assert fault from active output; both receivers observe it and gates remain off after fault clears, until explicit rearm. |
| Rearm | A deliberate rearm followed by a fresh command can restart only after the required wake-up and interlock delays. |

For a stop test, start the capture before active output and keep recording through
the entire specified hold window, including stop/fault release where applicable.
An all-zero recording cannot demonstrate that an active controller stopped.
Digital logic captures do not measure motor-current removal, contact opening,
analog backfeed, thermal limits or stopping distance.

The automated checker evaluates the declared output windows and wiring/interlock
rules. It cannot infer a correct stimulus from a case name, authenticate instrument
metadata, or prove that the requested PWM duty was applied. Correlate the raw
command and acknowledgement captures, measure duty/frequency, and record the
stimulus independently before accepting the end-to-end case. A matching wire
codec alone does not prove the AxiomOS host or its RP1 UART driver worked.

## Run the fixture

From the rover repository root:

```sh
python3 -m unittest discover -s bench -v

# Optional integration test against the external, read-only interface snapshot.
AXIOMOS_REPO=/home/utkarsh/Work/axiomOS python3 -m unittest discover -s bench -v

# Print synthetic packets only; neither command opens a serial device.
python3 bench/wire.py vectors
python3 bench/wire.py encode '{"type":"estop","assert":true}'

# A supplied synthetic recording exercises the checker without hardware.
python3 bench/trace.py bench/examples/synthetic-case.json \
  bench/examples/synthetic-capture.csv --output /tmp/rover-synthetic-report.json

# Decode a raw byte capture from one UART direction (binary, not ASCII hex).
python3 bench/wire.py decode /path/to/base-rx.bin

# Read a committed interface snapshot, compile its codec in this repo's cache,
# and compare it to the fixture. Requires git and rustc; AxiomOS is read-only.
python3 bench/check_compat.py --repo /home/utkarsh/Work/axiomOS \
  --commit 4f5aa9037832b9ee27145c5ffc87f4c3ca707e18

# After filling a copied manifest and acquiring the corresponding capture:
python3 bench/trace.py /path/to/case.json /path/to/capture.csv \
  --output /path/to/report.json
```

The logic CSV must have exactly these columns. Times are microseconds and signal
values are `0` or `1`; retain an initial sample and an explicit final sample.

```text
time_us,estop_n,fault_n,pwm_l,pwm_r,l_in1,l_in2,r_in3,r_in4,drv_ain1,drv_ain2,drv_bin1,drv_bin2,nsleep
```

`estop_n` is the hardware stop source, `fault_n` is the driver's fault source,
`pwm_l/r` are the FPGA gate outputs, and `l_in1/l_in2/r_in3/r_in4` are the RP
direction signals. The four `drv_*` signals are U4's gated outputs at U3.
`nsleep` is U3's stop input; software expiry must stop PWM even while this
hardware-stop input stays high. Check each buffered stop/fault receiver separately
as required by commissioning; those receiver channels are not in this CSV.

The saved [wire comparison](../bench/evidence/wire-compatibility.json) identifies
the inspected AxiomOS commit, source digest, fixture hashes and Rust compiler.
It covers six UART encodings and twelve decoder streams, including corruption,
resynchronization, incomplete frames and an in-payload sync byte. It establishes
software wire compatibility for those cases only. The FPGA packet fixture is
checked against the published source golden vector; this is not a synthesized
bitstream or a physical SPI timing result.

The [worked capture](../bench/examples/synthetic-capture.csv),
[case definition](../bench/examples/synthetic-case.json) and
[saved report](../bench/examples/synthetic-report.json) are synthetic. Their
short timing values exercise software branches and must not be used as physical
acceptance limits. No firmware or RTL executes when generating those signals.

## Progression

1. Exercise the fixture's offline tests and check compatibility with the supplied
   AxiomOS interface snapshot, without building in or writing to AxiomOS.
2. When its firmware and validated bitstream are available, complete the
   disconnected-motor cases above and retain their raw evidence.
3. Qualify one motor, then both, on the raised-wheel stand with a current-limited
   supply and the independent stop. Measure current, temperature, encoder phase,
   counts and stop/reverse rail behavior using the commissioning procedure.
4. Confirm actual Pi/Shrike/socket/cooler fit and use those measurements to settle
   any PCB or enclosure revision before fabrication release.

The fixture never sets `release-gates.json`. Physical release remains a separate
evidence review. Linux serial traffic proves the transport only; an AxiomOS
release test must identify the AxiomOS build that mediated the commands.

Sources: [Rev B electrical contract](electrical-contract.md),
[Vicharak internal bus guide](https://blog.vicharak.in/7-ways-your-mcu-can-talk-to-fpga-on-shrike/),
[TI DRV8833 datasheet](https://www.ti.com/lit/ds/symlink/drv8833.pdf).

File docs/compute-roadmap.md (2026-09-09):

# Compute swaps after AxiomOS v1.0

The July 2026 AxiomOS direction is Linux/CUDA for NVIDIA compute and AxiomOS for bounded control, advancing from two machines to one partitioned machine only after the boundary is demonstrated. This repository implements the common physical base and records that progression; it does not select or implement a hypervisor.

| Stage | Compute arrangement | Boundary to prove | Hardware change |
|---|---|---|---|
| A: first release rover | Raspberry Pi 5 running the qualified AxiomOS host/control build → Shrike | Command expiry, safe start, e-stop, watchdog, recovery | Pi tray on the common mounts |
| B: NVIDIA two-box | Linux/Jetson performs perception/CUDA; Pi/AxiomOS validates bounded intents and retains actuator authority | Linux stalls, crashes and stale/reordered traffic cannot extend actuator authority | Adapter tray/pod and separate host power; base carrier unchanged |
| C: same-SoC research | Linux and AxiomOS on separately owned cores/devices of a supported NVIDIA platform | Memory/DMA/interrupt/timer isolation, resource starvation, reset and boot ownership | Qualified compute pod; base carrier unchanged |

Stage B is the working architecture to qualify before C. A Linux-only direct-to-actuator run is a transport test, not evidence that AxiomOS mediated the command. Stage C depends on the actual NVIDIA SoC, firmware and supported partitioning mechanism; CUDA remains with Linux. Do not infer isolation from successful dual boot or ordinary Linux processes.

All trays share four M3 clearance holes at `(±85, ±65)` mm on a 200 × 160 mm tray. The first Pi mounting grid is 58 × 49 mm. Jetson hardware, cooling, mass distribution and connector envelopes require their own measured adapter; no unspecified Jetson board is declared to fit.

The base controller, sensor, motor driver, gate, e-stop and actuator wiring stay fixed. Swaps are **power-off**, mechanically fastened and strain-relieved. One host owns the isolator at a time: use J1 for Pi or J12 for an alternate host, with the Pi electrically removed before using J12. Use separately qualified host power; J1's 3.3 V feeds only its side of U1, not the other processor or motors.

## Release comparisons

Run the same [commissioning cases](commissioning.md) with the same current limits, battery state, actuator firmware and bitstream, then change only the compute configuration. Record median, tail and maximum observed command-to-gated-output latency; retain complete captures and dropped/error frame counts. Test fault cases as well as nominal motion. A clean Linux/CUDA benchmark does not replace the physical control evidence.

The currently inspected AxiomOS baseline (`4f5aa90`, `firmware/shrike/README.md`) states that its Shrike implementation remains safe-low/non-operational pending a validated bitstream/timing manifest and atomic UART/watchdog/e-stop adapter. This hardware design does not remove that prerequisite or introduce a second wire protocol.

Provenance: the user's post-v1.0 direction and `/home/utkarsh/Work/axiom-lab/roadmap/architecture-north-star.md` (two-box → one-box direction). These are references, not build dependencies; this repository has no AxiomOS submodule, worktree relationship or symlink. The unrelated `Work/linux-multikernel` project is not a design source.

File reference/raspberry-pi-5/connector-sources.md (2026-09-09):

# RevB connector source notes

All dimensions are nominal millimetres. Validate the fitted stack with the
actual purchased parts.

## Pi 5 GPIO datum and selected carrier socket

Official Raspberry Pi sources: [mechanical/STEP index](https://www.raspberrypi.com/documentation/computers/raspberry-pi.html#schematics-and-mechanical-drawings), [Pi 5 mechanical drawing](https://pip.raspberrypi.com/documents/RP-008347-DS), and the local unmodified [RP-010083-CA STEP archive](RP-010083-CA-1-rpi-5-3D-STEP-no-graphics.zip).

From the official STEP, with the Pi in top view, USB ports at right, and the
85 x 56 outline's top-left corner as `(0,0)`: pin 1 is `(8.37,4.77)` and pin
2 is `(8.37,2.23)`. Odd pins are `(8.37 + 2.54k,4.77)`; even pins are
`(8.37 + 2.54k,2.23)`, for `k=0..19`. Pin 1 is the square-marked, lower
visible row in the official mechanical drawing. The STEP GPIO post reaches
8.54 above the Pi PCB top.

Selected part: **Samtec ESQ-120-24-G-D**, 2 x 20, elevated THT socket.

* [Product page](https://www.samtec.com/products/esq-120-24-g-d)
* [Series catalogue, F-226](https://suddendocs.samtec.com/catalog_english/esq_th.pdf)
* [Exact part drawing](https://suddendocs.samtec.com/prints/esq-1xx-xx-x-x-xxx-xx-x-xx-mkt.pdf)
* [ESQ THT footprint drawing](https://suddendocs.samtec.com/prints/esq-sdt.pdf)

The `-24` lead style has `B=13.59` (socket body height from PCB mounting
surface to mating face) and `A=9.65` tail. At a carrier underside height of
16.50 above the Pi PCB, the Pi post insertion is `13.59 + 8.54 - 16.50 =
5.63`, within Samtec's 3.68--6.35 insertion-depth range.

Use a 1.02 diameter PTH drill, 2.54 pitch in each direction. For 20 positions
per row, the hole-centre span is `19 x 2.54 = 48.26`; the ESQ moulded body is
`(20 x 2.54) + 0.51 = 51.31` long and 4.95 wide (`.195 REF`). It therefore
overhangs the end-hole centres by 1.525 at each end. The Samtec footprint
drawing gives the drill but no copper-pad outer diameter; select pad OD and
annular ring from the fabricator rules rather than treating 1.02 as a pad OD.

For a socket on the carrier underside, preserve physical pin 1-to-pin 1 XY
coincidence; place/mirror the footprint in CAD rather than mirroring its pin
numbering by hand.

## Shrike sockets

Use **2 x Samtec SSW-119-01-G-S**, each 1 x 19, 2.54 pitch, vertical THT.

* [Product page](https://www.samtec.com/products/ssw-119-01-g-s)
* [Series catalogue](https://suddendocs.samtec.com/catalog_english/ssw_th.pdf)
* [Exact part drawing](https://suddendocs.samtec.com/prints/ssw-1xx-xx-xxx-x-xx-xxx-xx-mkt.pdf)
* [Single-row vertical footprint drawing](https://suddendocs.samtec.com/prints/ssw-svs.pdf)

`-01` has a 2.64 tail. The 8.51 `.335 REF` dimension is the moulded socket
body height above the mounting surface; the tail is dimensioned separately,
so it is not included in 8.51. Samtec specifies 3.68--6.35 mating insertion
depth. Use 1.02 PTH drill on 2.54 centres; the source drawing does not state a
copper-pad OD.

For 19 positions, body length is `(19 x 2.54) + 0.51 = 48.77`; body width is
2.41 (`.095 REF`). The end-hole-centre span is `18 x 2.54 = 45.72`, hence
1.525 body overhang beyond each end-hole centre.

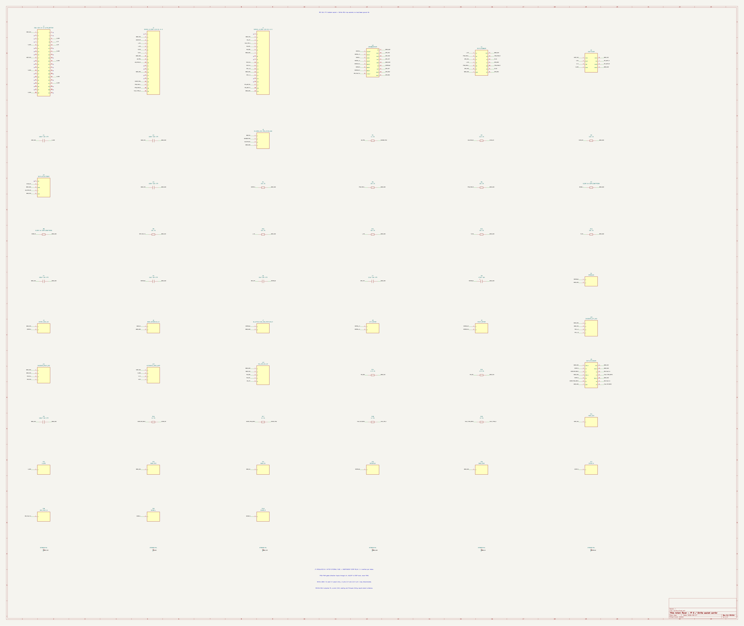
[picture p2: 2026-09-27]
electronics/out/schematic/carrier.png

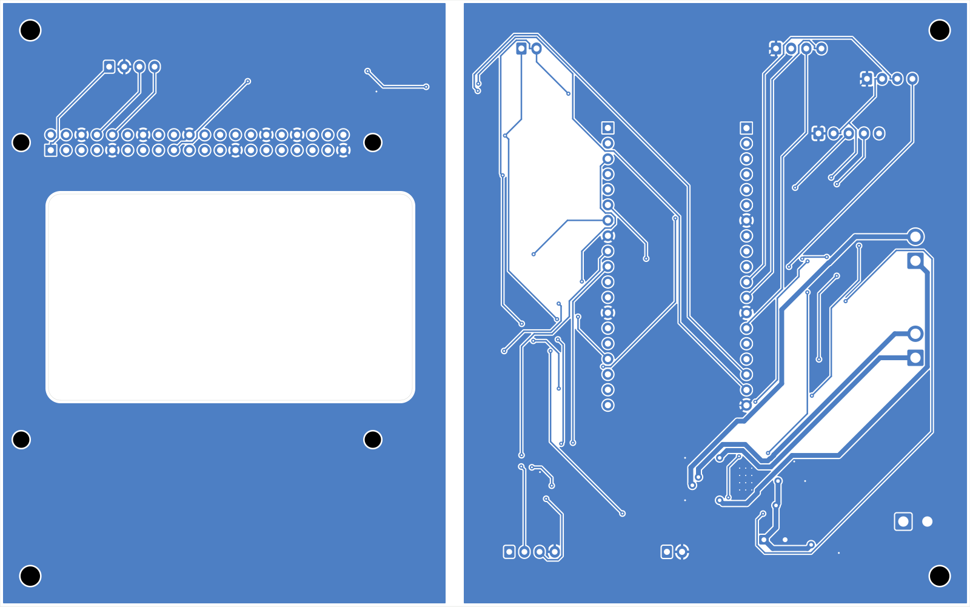
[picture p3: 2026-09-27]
electronics/out/carrier-bottom.png

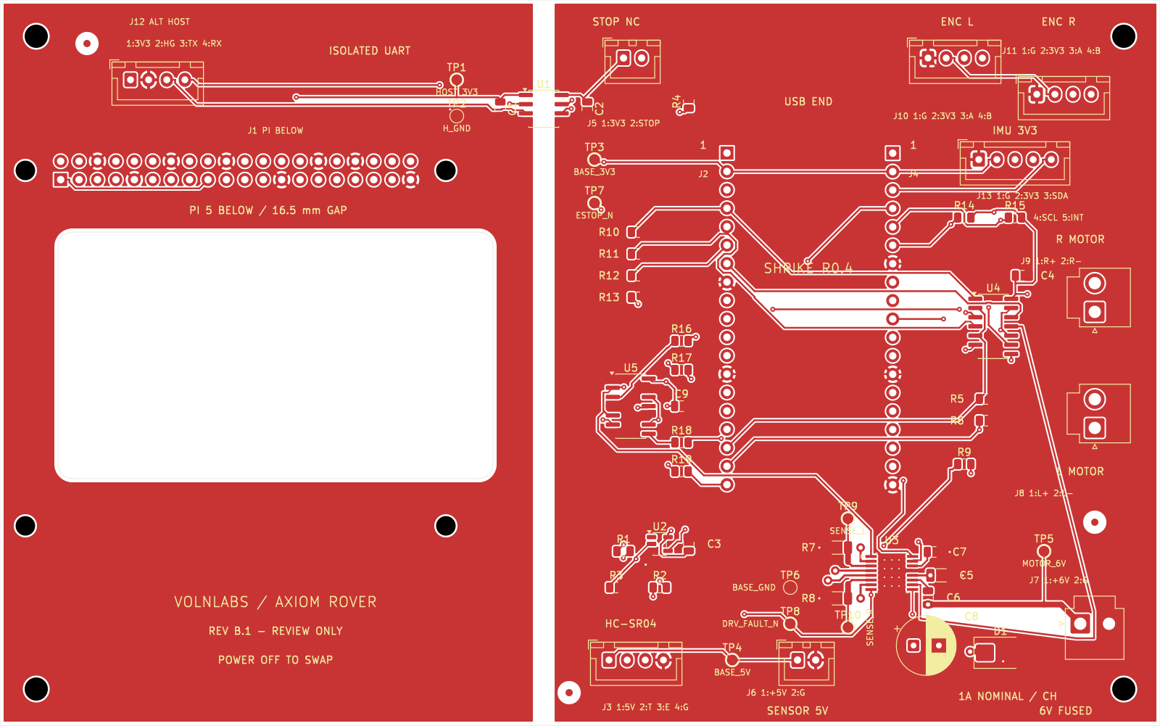
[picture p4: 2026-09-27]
electronics/out/carrier-top.png

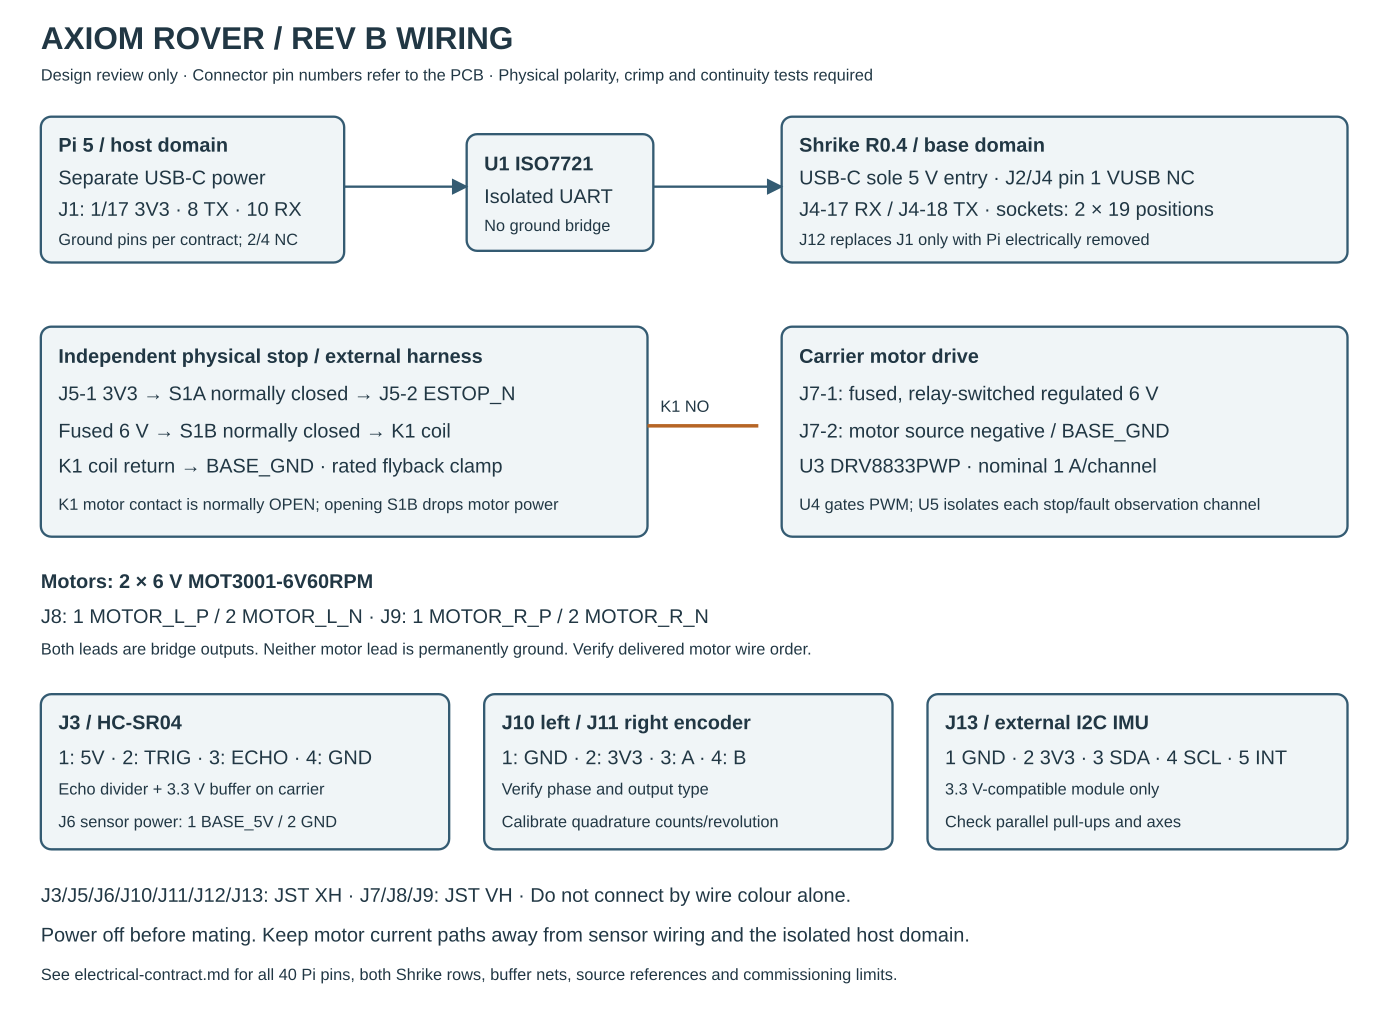
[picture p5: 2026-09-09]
docs/harness.png

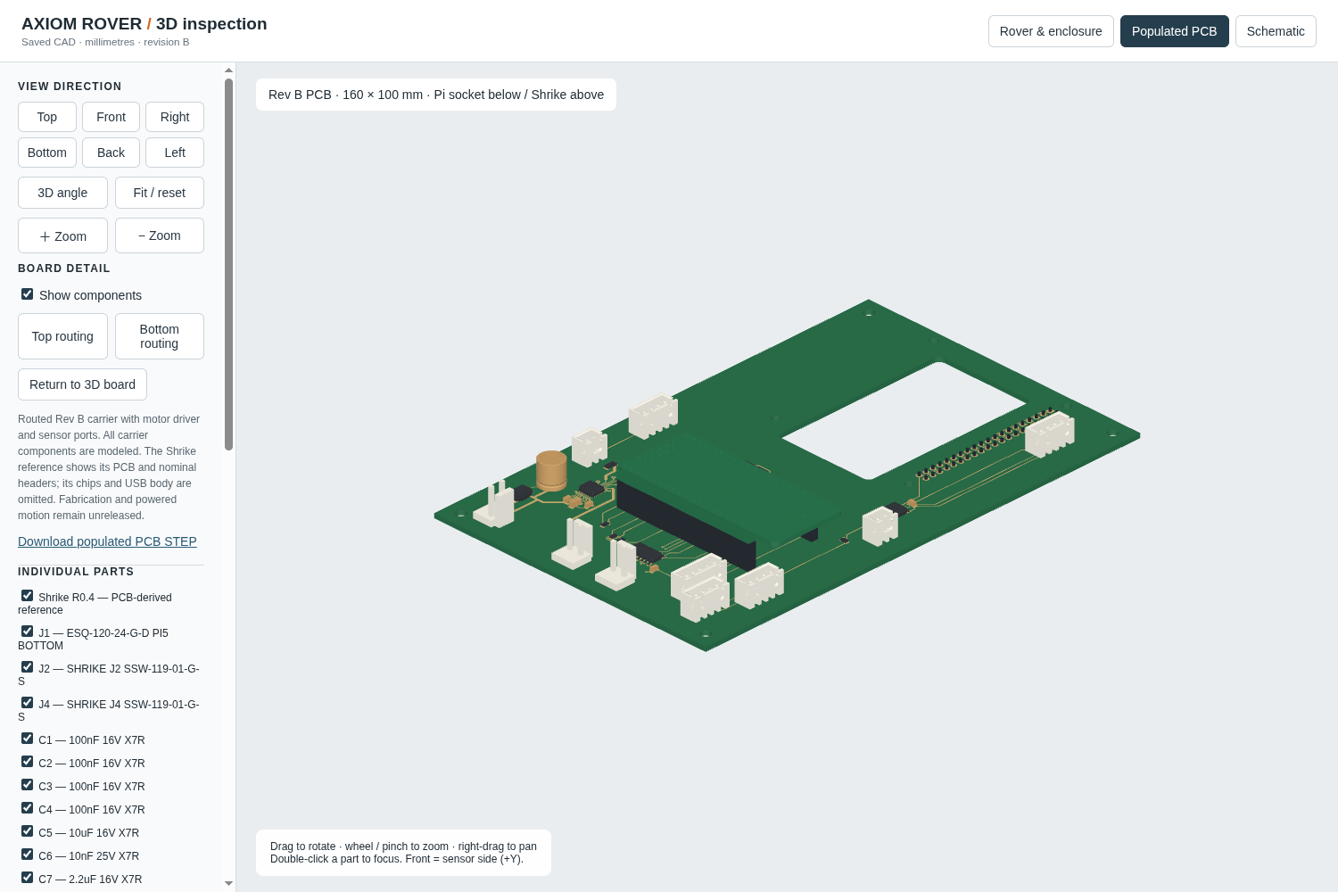
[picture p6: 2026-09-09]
viewer/pcb-isometric.png

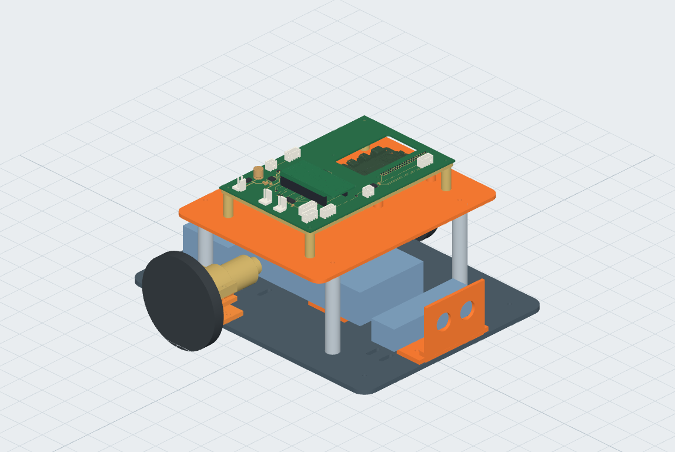
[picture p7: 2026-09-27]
viewer/rover-preview.png

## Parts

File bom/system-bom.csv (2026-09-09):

line | item | manufacturer_part_or_requirement | quantity | unit_cost_inr_low | unit_cost_inr_high | extended_inr_low | extended_inr_high | source_or_basis | status
1 | RevB carrier bare PCB | 160x100mm 2-layer FR-4 1.6mm first article | 1 | 1800 | 3500 | 1800 | 3500 | estimate only; vendor quote required | estimate
2 | Carrier assembly and electronics | DRV8833PWPR U4 U5 ISO7721DR protection passives and assembly/stencil | 1 | 2500 | 5000 | 2500 | 5000 | estimate only; final BOM/PnP quote required | estimate
3 | Pi carrier socket | Samtec ESQ-120-24-G-D 2x20 THT | 1 | 800 | 2000 | 800 | 2000 | estimate only; https://www.samtec.com/products/esq-120-24-g-d | estimate
4 | Shrike sockets | Samtec SSW-119-01-G-S 1x19 THT | 2 | 250 | 800 | 500 | 1600 | estimate only; https://www.samtec.com/products/ssw-119-01-g-s | estimate
5 | Carrier harnesses and contacts | JST XH sensor/encoder/IMU and JST VH motor/6V connectors plus wire strain relief | 1 | 800 | 2000 | 800 | 2000 | estimate only; selected families from electronics/generate.py | estimate
6 | Encoder gearmotor | ThinkRobotics MOT3001-6V60RPM 6V 60RPM encoder motor 25mm | 2 | 1179.99 | 1179.99 | 2359.98 | 2359.98 | user-selected price INR1179.99 each; order/receipt not recorded | price datum only
7 | Wheels | Pololu 3690 80x10mm wheel pair with 4mm D-bore collets | 1 | 862 | 2000 | 862 | 2000 | explicit estimate envelope; quote required | estimate
8 | HC-SR04 and external I2C IMU | HC-SR04 plus 3.3V I2C IMU with interrupt harness | 1 | 1000 | 4500 | 1000 | 4500 | estimate only; exact IMU SKU not selected | estimate
9 | Emergency stop relay fuse and high-current wiring | two-pole NC stop plus normally-open relay contact and fuse holder/fuse and 6V wiring rated from measured stall current | 1 | 1500 | 5000 | 1500 | 5000 | estimate only; no relay/fuse/wire rating selected | estimate
10 | Motor 6V power source | externally charged regulated 6V source compatible with final current and transients | 1 | 2000 | 4500 | 2000 | 4500 | estimate only; quote and electrical qualification required | estimate
11 | Shrike USB 5V source | external 5V source and USB-C lead for Shrike only | 1 | 1200 | 2500 | 1200 | 2500 | estimate only; do not backfeed through Pi 5V | estimate
12 | Pi5 power source | 5V/5A-capable source at Pi USB-C plug | 1 | 2500 | 4500 | 2500 | 4500 | estimate only; Pi and base power are separate | estimate
13 | Chassis mounts enclosure and hardware | RevB motor mounts wheel hardware carrier supports and M3 hardware | 1 | 3000 | 6000 | 3000 | 6000 | estimate only; mechanical fit still required | estimate
14 | Revision reserve | retained for rework/shipping/spares | 1 | 6000 | 6000 | 6000 | 6000 | budget reserve not a vendor quote | reserve
TOTAL | Prototype excluding Pi5/Shrike boards and instruments |  |  |  |  | 26821.98 | 51459.98 | non-reserve subtotal INR20821.98-INR45459.98; low is within INR24000 first-order target before INR6000 reserve; high exceeds INR30000 cap; obtain quotes before order | estimate

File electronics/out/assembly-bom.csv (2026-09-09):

Reference | Value / MPN | Footprint | Quantity
J1 | ESQ-120-24-G-D_PI5_BOTTOM | Rover:Pi5_Socket_2x20 | 1
J2 | SHRIKE_J2_SSW-119-01-G-S | Rover:SSW-119-01-G-S | 1
J4 | SHRIKE_J4_SSW-119-01-G-S | Rover:SSW-119-01-G-S | 1
U3 | DRV8833PWPR | Package_SO:HTSSOP-16-1EP_4.4x5mm_P0.65mm_EP3.4x5mm_Mask2.46x2.31mm_ThermalVias | 1
U4 | SN74LVC08ADR | Package_SO:SOIC-14_3.9x8.7mm_P1.27mm | 1
U1 | ISO7721DR | Package_SO:SOIC-8_3.9x4.9mm_P1.27mm | 1
C1 | 100nF 16V X7R | Capacitor_SMD:C_0805_2012Metric | 1
C2 | 100nF 16V X7R | Capacitor_SMD:C_0805_2012Metric | 1
J3 | HC_SR04_VCC_TRIG_ECHO_GND | Connector_JST:JST_XH_B4B-XH-A_1x04_P2.50mm_Vertical | 1
R1 | 1k 1% | Resistor_SMD:R_0805_2012Metric | 1
R2 | 2.2k 1% | Resistor_SMD:R_0805_2012Metric | 1
R3 | 3.3k 1% | Resistor_SMD:R_0805_2012Metric | 1
U2 | SN74LVC1G17DBVR | Package_TO_SOT_SMD:SOT-23-5 | 1
C3 | 100nF 16V X7R | Capacitor_SMD:C_0805_2012Metric | 1
R4 | 10k 1% | Resistor_SMD:R_0805_2012Metric | 1
R5 | 10k 1% | Resistor_SMD:R_0805_2012Metric | 1
R6 | 10k 1% | Resistor_SMD:R_0805_2012Metric | 1
R7 | 0.20R 1W CSRT1206FTR200 | Resistor_SMD:R_1206_3216Metric | 1
R8 | 0.20R 1W CSRT1206FTR200 | Resistor_SMD:R_1206_3216Metric | 1
R9 | 10k 1% | Resistor_SMD:R_0805_2012Metric | 1
R10 | 10k 1% | Resistor_SMD:R_0805_2012Metric | 1
R11 | 10k 1% | Resistor_SMD:R_0805_2012Metric | 1
R12 | 10k 1% | Resistor_SMD:R_0805_2012Metric | 1
R13 | 10k 1% | Resistor_SMD:R_0805_2012Metric | 1
C4 | 100nF 16V X7R | Capacitor_SMD:C_0805_2012Metric | 1
C5 | 10uF 16V X7R | Capacitor_SMD:C_1206_3216Metric | 1
C6 | 10nF 25V X7R | Capacitor_SMD:C_0805_2012Metric | 1
C7 | 2.2uF 16V X7R | Capacitor_SMD:C_0805_2012Metric | 1
C8 | 470uF 16V | Capacitor_THT:CP_Radial_D8.0mm_P3.50mm | 1
D1 | SMBJ6.0A | Diode_SMD:D_SMB | 1
J5 | ESTOP_LOGIC_NC | Connector_JST:JST_XH_B2B-XH-A_1x02_P2.50mm_Vertical | 1
J6 | BASE_SENSOR_5V_IN | Connector_JST:JST_XH_B2B-XH-A_1x02_P2.50mm_Vertical | 1
J7 | 6V_AFTER_FUSE_AND_STOP_RELAY | Connector_JST:JST_VH_B2P-VH_1x02_P3.96mm_Vertical | 1
J8 | LEFT_MOTOR | Connector_JST:JST_VH_B2P-VH_1x02_P3.96mm_Vertical | 1
J9 | RIGHT_MOTOR | Connector_JST:JST_VH_B2P-VH_1x02_P3.96mm_Vertical | 1
J10 | ENCODER_LEFT_3V3 | Connector_JST:JST_XH_B4B-XH-A_1x04_P2.50mm_Vertical | 1
J11 | ENCODER_RIGHT_3V3 | Connector_JST:JST_XH_B4B-XH-A_1x04_P2.50mm_Vertical | 1
J12 | ALTERNATE_HOST_UART | Connector_JST:JST_XH_B4B-XH-A_1x04_P2.50mm_Vertical | 1
J13 | IMU_3V3_I2C_INT | Connector_JST:JST_XH_B5B-XH-A_1x05_P2.50mm_Vertical | 1
R14 | 4.7k 1% | Resistor_SMD:R_0805_2012Metric | 1
R15 | 4.7k 1% | Resistor_SMD:R_0805_2012Metric | 1
U5 | SN74LVC125ADR | Package_SO:SOIC-14_3.9x8.7mm_P1.27mm | 1
C9 | 100nF 16V X7R | Capacitor_SMD:C_0805_2012Metric | 1
R16 | 1k 1% | Resistor_SMD:R_0805_2012Metric | 1
R17 | 1k 1% | Resistor_SMD:R_0805_2012Metric | 1
R18 | 1k 1% | Resistor_SMD:R_0805_2012Metric | 1
R19 | 1k 1% | Resistor_SMD:R_0805_2012Metric | 1

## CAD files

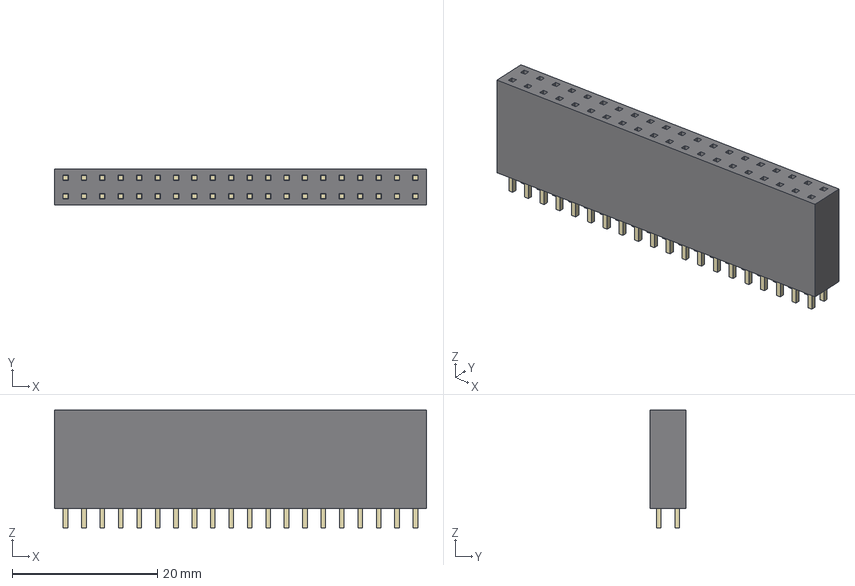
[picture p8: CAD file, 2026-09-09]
electronics/models/Pi5_Socket_2x20.step
51.3 x 4.95 x 16.2 mm
nominal_socket_body
tail_1
tail_2
tail_3
tail_4
tail_5
tail_6
tail_7
tail_8
tail_9
tail_10
tail_11
tail_12
tail_13
tail_14
tail_15
tail_16
tail_17
tail_18
tail_19
tail_20
tail_21
tail_22
tail_23
tail_24
tail_25
tail_26
tail_27
tail_28
tail_29
tail_30
tail_31
tail_32
tail_33
tail_34
tail_35
tail_36
tail_37
tail_38
tail_39
tail_40

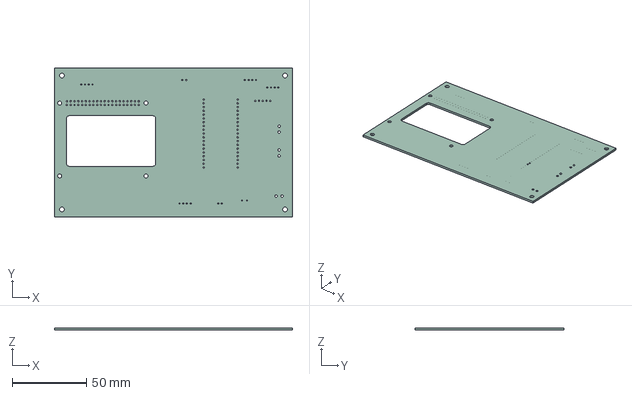
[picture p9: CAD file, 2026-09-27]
electronics/out/carrier-bare-board.step
160.0 x 100.0 x 1.51 mm

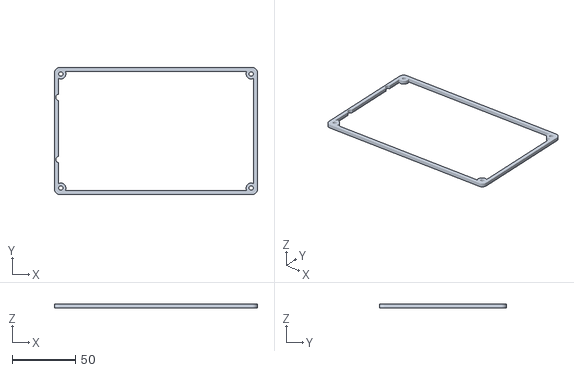
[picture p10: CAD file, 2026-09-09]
mechanical/out/carrier_frame.stl
160.0 x 100.0 x 3.00

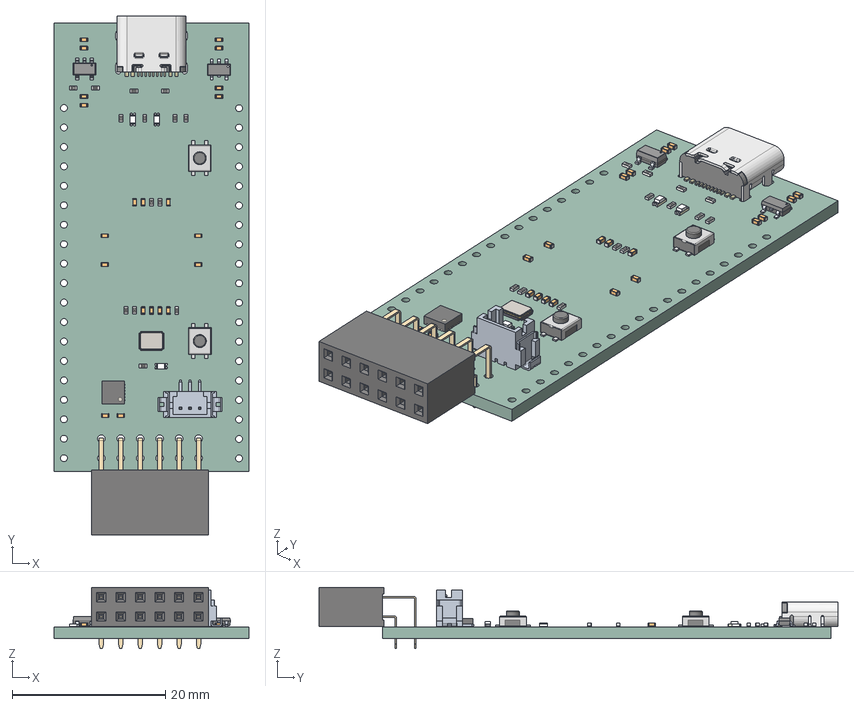
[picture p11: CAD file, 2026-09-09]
reference/shrike-r04/Shrike-lite.step
25.4 x 67.8 x 7.98 mm
kicad_embedded_BCDEFA549BD92648B89B079BD65F0360 x 3
kicad_embedded_4BF2C315065B03F2EDB6664BF6E06EBC x 14
PinsArrayL
PinsArrayR
Shrike-lite 1.18.1
kicad_embedded_23D3BBCB113E4F12280F49A9A7372AAE
kicad_embedded_5DA03CE9F3160850AF560ED0F9C2898B
kicad_embedded_72BB9CE2D1522D823768491D5397E6AB x 2
kicad_embedded_29C47ED5F14A361E81E1A38E2F171F89
kicad_embedded_BBED6F8B535C06F9EA1D5AD73DD78B29
ConPins
PcbPins
Mold
Frame
Shrike-lite_PCB

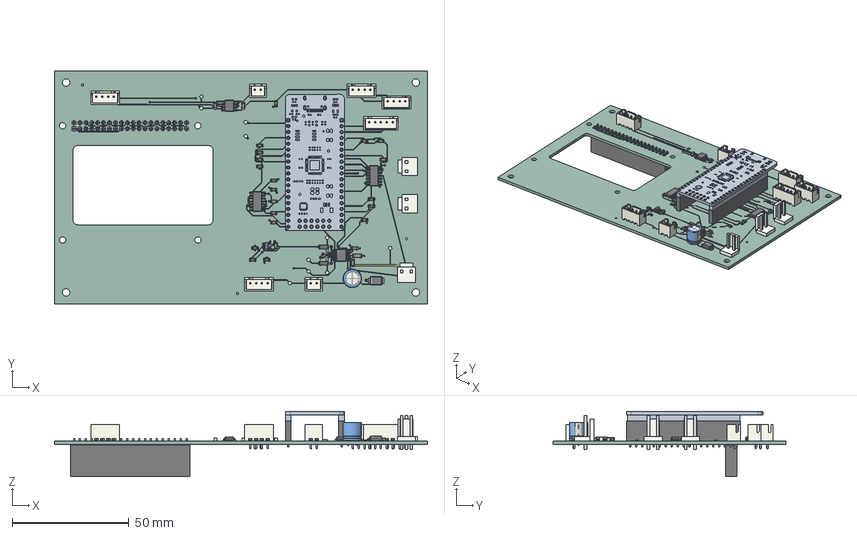
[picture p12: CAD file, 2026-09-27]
viewer/carrier-populated.step
160.0 x 100.0 x 27.9 mm
JST_B4B_XH_A x 4
CP_Radial_D80mm_P350mm
C_0805_2012Metric x 7
SOIC_14_39x87mm_P127mm x 2
R_0805_2012Metric x 17
SOIC_8_39x49mm_P127mm
TSSOP_16_1EP_44x5mm_Pitch065mm_EP34x5mm
nominal_socket_body x 3
tail_1 x 3
tail_2 x 3
tail_3 x 3
tail_4 x 3
tail_5 x 3
tail_6 x 3
tail_7 x 3
tail_8 x 3
tail_9 x 3
tail_10 x 3
tail_11 x 3
tail_12 x 3
tail_13 x 3
tail_14 x 3
tail_15 x 3
tail_16 x 3
tail_17 x 3
tail_18 x 3
tail_19 x 3
R_1206_3216Metric x 2
nominal_VH_body x 3
pin_1 x 3
pin_2 x 3
JST_B2B_XH_A x 2
C_1206_3216Metric
shrike_pcbCAD
D_SMB
JST_B5B_XH_A
SOT_23_5
tail_20
tail_21
tail_22
tail_23
tail_24
tail_25
tail_26
tail_27
tail_28
tail_29
tail_30
tail_31
tail_32
tail_33
tail_34
tail_35
tail_36
tail_37
tail_38
tail_39
tail_40
carrier_copper
carrier_pad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

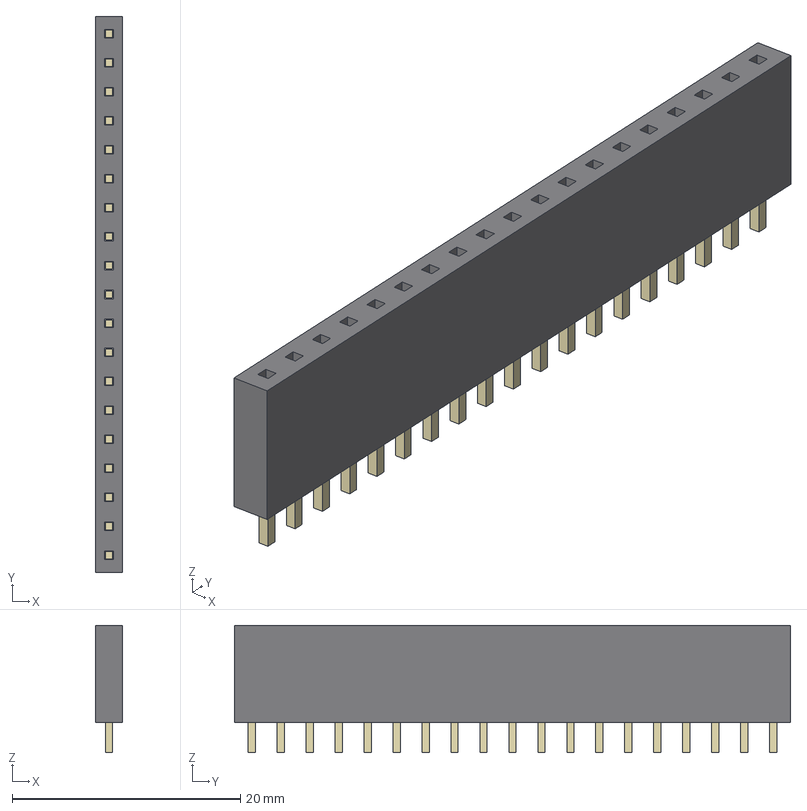
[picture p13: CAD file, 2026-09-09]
electronics/models/SSW-119-01-G-S.step
2.41 x 48.8 x 11.2 mm
nominal_socket_body
tail_1
tail_2
tail_3
tail_4
tail_5
tail_6
tail_7
tail_8
tail_9
tail_10
tail_11
tail_12
tail_13
tail_14
tail_15
tail_16
tail_17
tail_18
tail_19

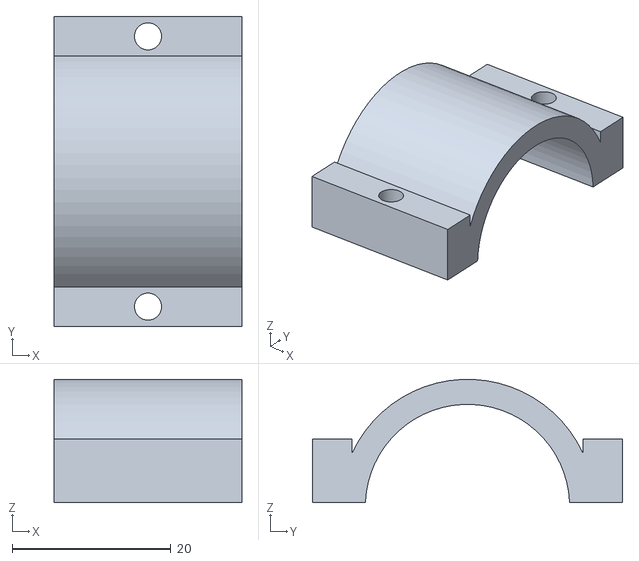
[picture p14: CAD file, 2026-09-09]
mechanical/out/right_motor_clamp_cap.stl
23.6 x 39.0 x 15.5

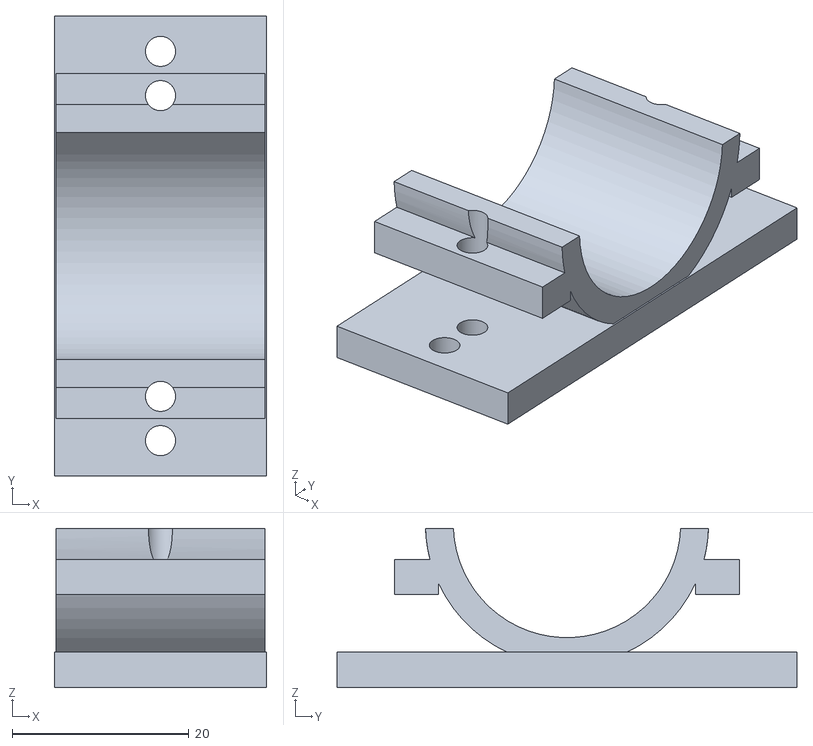
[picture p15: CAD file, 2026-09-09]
mechanical/out/left_motor_bracket.stl
24.0 x 52.0 x 18.0

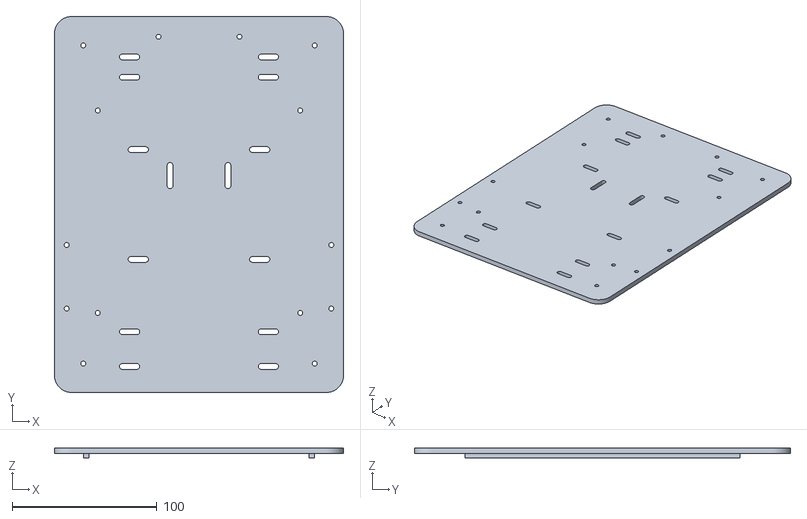
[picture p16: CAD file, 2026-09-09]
mechanical/out/base_chassis.stl
200.0 x 260.0 x 7.00

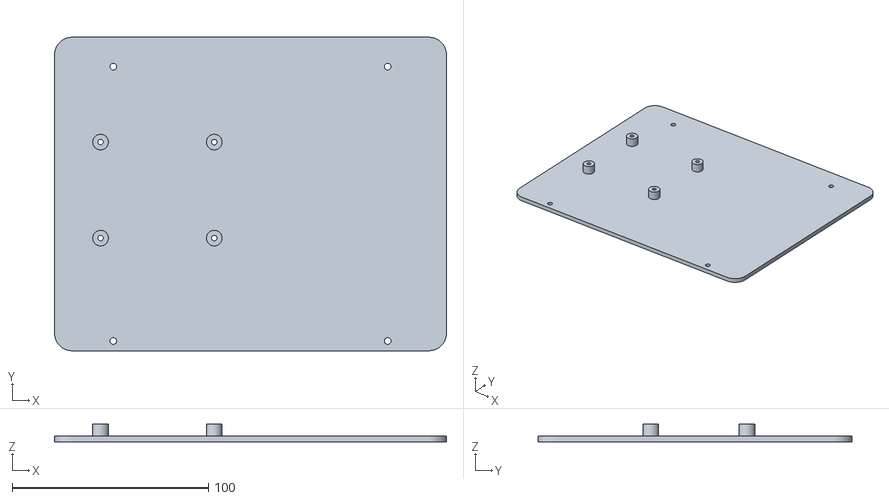
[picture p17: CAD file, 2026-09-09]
mechanical/out/tray.stl
200.0 x 160.0 x 9.00

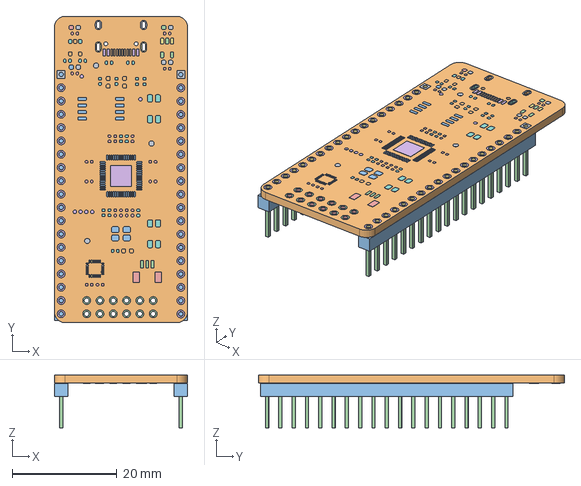
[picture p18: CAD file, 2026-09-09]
mechanical/out/shrike-module.step
25.4 x 58.5 x 10.1 mm

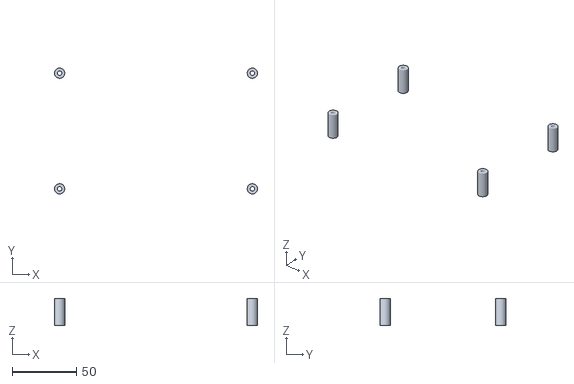
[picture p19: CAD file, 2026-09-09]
mechanical/out/carrier_posts.stl
158.0 x 98.0 x 21.1

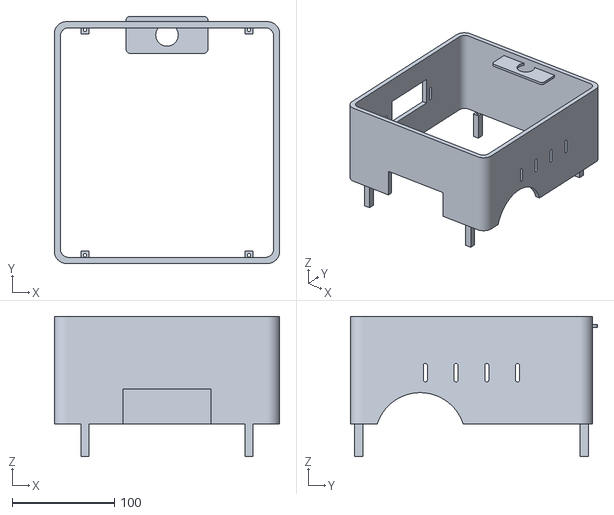
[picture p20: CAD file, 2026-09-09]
mechanical/out/vented_shell.stl
220.0 x 241.0 x 137.0

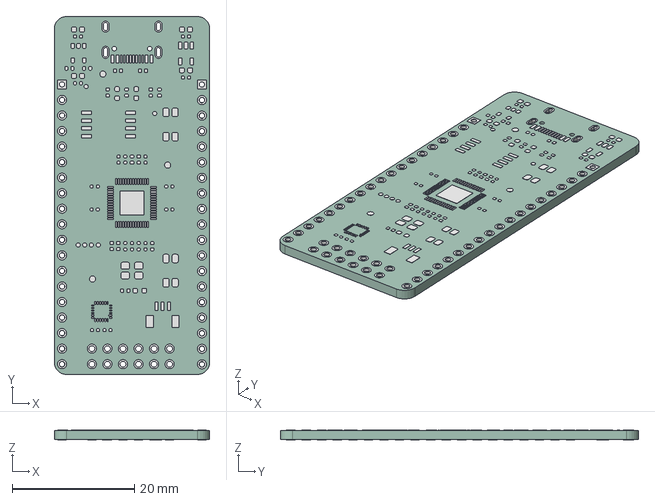
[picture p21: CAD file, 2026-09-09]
mechanical/out/shrike-pcb-derived.step
25.4 x 58.5 x 1.57 mm
Shrike-lite_pad
Shrike-lite_PCB

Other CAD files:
mechanical/out/axiom_rover_assembly.step
reference/raspberry-pi-5/rpi-5b_no_graphics.step
mechanical/out/left_motor_clamp_cap.stl
mechanical/out/right_motor_bracket.stl
mechanical/out/caster_fixture.stl
mechanical/out/sensor_bracket.stl
mechanical/out/test_stand.stl
mechanical/out/tray_posts.stl

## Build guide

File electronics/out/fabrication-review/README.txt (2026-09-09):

DESIGN REVIEW ONLY — not released for fabrication. Read docs/commissioning.md and release-gates.json. Exact vendor order codes, power ratings and physical fit remain unqualified.

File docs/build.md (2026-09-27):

# Reproduce Rev B.1 review artifacts

Install [Git LFS](https://github.com/git-lfs/git-lfs), then run these commands
from your cloned repository to obtain the large CAD and viewer files:

```sh
git lfs install --local
git lfs pull
git lfs fsck
```

The assembly STEP, Pi reference STEP and `viewer/meshes.json` are tracked in
LFS; their checked-out contents remain the original full files. The six local
commits were migrated before the first successful GitHub push. Historical audit
references retain their original commit IDs; [lfs-commit-map.csv](lfs-commit-map.csv)
maps those IDs to the corresponding migrated commits.

Open `electronics/carrier.kicad_pro` in KiCad 10.0.6. The saved board is editable
and routed. `electronics/generate.py` is the parametric source; regenerating it
overwrites manual KiCad edits and removes routing. Preserve manual revisions
before regenerating. None of these commands authorizes fabrication or motion.

Use CadQuery 2.6.1 from `mechanical/requirements.txt` in a repository-local
`.venv`. Download the pinned [Freerouting 2.4.1 release](https://github.com/freerouting/freerouting/releases/tag/v2.4.1)
to `.cache/cad/freerouting-2.4.1.jar` before routing.

```sh
uv venv --python python3.12 .venv
uv pip install --python .venv/bin/python -r mechanical/requirements.txt
mkdir -p .cache/cad/router
curl -fL https://github.com/freerouting/freerouting/releases/download/v2.4.1/freerouting-2.4.1.jar -o .cache/cad/freerouting-2.4.1.jar

# From the repository root, rebuild mechanical references and printable parts.
.venv/bin/python mechanical/axiom_rover.py --output mechanical/out
.venv/bin/python viewer/export_meshes.py --socket-models-only

# Reproduce the reviewed board using its matching saved routing session.
# The generator locks the short local motor/power routes before export.
.cache/cad/kicad-10.0.6-x86_64-lite.AppImage python3.11 electronics/generate.py
.cache/cad/kicad-10.0.6-x86_64-lite.AppImage python3.11 electronics/generate.py --import-session electronics/out/carrier.ses

# Remove only unused vias identified by a fresh native DRC report; rerun DRC below.
.cache/cad/kicad-10.0.6-x86_64-lite.AppImage kicad-cli pcb drc --format json --schematic-parity -o electronics/out/drc.json electronics/carrier.kicad_pcb
.cache/cad/kicad-10.0.6-x86_64-lite.AppImage python3.11 electronics/generate.py --clean-dangling-vias electronics/out/drc.json
.cache/cad/kicad-10.0.6-x86_64-lite.AppImage kicad-cli pcb drc --format json --schematic-parity -o electronics/out/drc.json electronics/carrier.kicad_pcb

# Export only after the fresh board has been routed and checked.
SSL_CERT_FILE=/etc/ssl/certs/ca-certificates.crt .cache/cad/kicad-10.0.6-x86_64-lite.AppImage python3.11 tools/prepare-pcb-models.py
python3 tools/export-electronics.py --kicad .cache/cad/kicad-10.0.6-x86_64-lite.AppImage
.venv/bin/python tools/check-assembly-fit.py
.venv/bin/python viewer/export_meshes.py
rsvg-convert -w 3200 electronics/out/schematic/carrier.svg -o electronics/out/schematic/carrier.png
rsvg-convert -w 1600 electronics/out/carrier-top.svg -o electronics/out/carrier-top.png
rsvg-convert -w 1600 electronics/out/carrier-bottom.svg -o electronics/out/carrier-bottom.png
python3 tools/check-viewer.py
python3 tools/check-artifacts.py
python3 -m http.server 8765 --bind 127.0.0.1
```

Stop if a command fails. `check-artifacts.py` checks source hashes, native
ERC/DRC/parity, actual pad/net mappings, mechanical reports, viewer geometry
freshness and BOM arithmetic. Open `http://127.0.0.1:8765/viewer/?test=1` for
the browser controls check. `tools/check-viewer.py` runs it using installed Chromium
and saves `viewer/browser-check.json` plus a screenshot. Logs are evidence
for this revision only.

For a changed layout, route the newly generated DSN instead of importing an
older session:

```sh
java -Djava.awt.headless=true -jar .cache/cad/freerouting-2.4.1.jar --gui.enabled=false -da --api_server.enabled=false --user_data_path=.cache/cad/router -de electronics/out/carrier.dsn -do electronics/out/carrier.ses -mp 25 -mt 1
```

The saved B.1 session includes the completed 0.25 mm TP5 probe branch from the
0.8 mm VM trunk. After a new autoroute, complete any remaining connections and
retain them in the session; require zero native DRC/connectivity/parity findings.
Freerouting can report unconnected fine-pitch escapes that are already locked
in KiCad, so its completion status alone is insufficient.
 Motor breakouts are locked 0.30 mm necks; default motor trunks are
0.8 mm. Do not replace these with unrestricted fine-pitch traces merely to
obtain a successful route.

Use `reference/raspberry-pi-5/connector-sources.md` for socket dimensions,
`docs/electrical-contract.md` and `docs/harness.svg` for wiring, and
`docs/commissioning.md` for physical acceptance. The carrier must be powered
off, lifted at least 7 mm to disengage the Pi header, and removed with its
perimeter frame. Unbolt the Pi, lift it 2 mm, then slide it through the side
opening. Sensor and
power harnesses require rated contacts, polarity checks and strain relief.

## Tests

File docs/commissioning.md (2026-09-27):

# Rev B.1 first article and commissioning

All entries are **NOT RUN**. This procedure creates evidence; it does not
authorize fabrication, energizing a motor, or a release until the recorded
acceptance limits pass.

## Before power

1. Inspect the 160 x 100 mm carrier, bottom-side `ESQ-120-24-G-D`, and both
   `SSW-119-01-G-S` Shrike sockets against the current schematic and
   `reference/raspberry-pi-5/connector-sources.md`. Check connector pin labels,
   three top fiducials and low-current through-hole ground thermal relief.
2. Dry-fit Pi 5, carrier, and Shrike. Confirm the nominal 16.5 mm carrier
   underside gap, socket engagement, no cooler collision, and J1/J2/J4 pin-1
   orientation. To remove Pi, power off, lift the unscrewed carrier at least
   7 mm to disengage J1, remove the carrier and perimeter frame, unbolt the Pi,
   lift it 2 mm, then slide it left through the service opening. Do not slide a
   mated header sideways or force sockets.
3. Meter every J2/J4 connection in `electrical-contract.md` against the
   delivered Shrike. Confirm buffered `FAULT_FPGA_N` reaches J2-19/F_GPIO7 and
   `FAULT_RP_N` reaches J4-4/RP GPIO28. Confirm Pi pins 2 and 4 are NC.
4. Confirm continuity and polarity for motor, encoder, HC-SR04, IMU, fuse,
   stop contact, and relay coil. Motor lead order, encoder phase, and encoder
   CPR are unknown until measured.
5. With no power attached, verify no short between `H_GND` and `BASE_GND`, no
   6 V-to-logic short, and correct NC stop behavior at J5/U3 `nSLEEP`.
6. Inspect top-accessible `H_GND`, `BASE_GND`, `HOST_3V3`, `BASE_3V3`,
   `BASE_5V`, `MOTOR_6V`, `ESTOP_N`, `DRV_FAULT_N`, `SENSE_L` and `SENSE_R`
   pads. Meter their net identity and check probe clearance before power.

## Power and safety sequence

1. Power Shrike only through USB-C. Keep Pi 5 V pins 2/4 disconnected.
2. Power Pi and base logic separately. Check isolated UART, HC-SR04 echo
   buffer, encoder 3.3 V, and IMU I2C pull-ups before attaching 6 V.
3. Test open stop-loop, broken stop-loop, and reset with motor 6 V disabled.
   U3 `nSLEEP` must be a stop level; it must not carry PWM.
4. Verify the independent fuse/relay stop path removes `MOTOR_6V` at J7 while
   logic remains powered. Record relay drop-out and rail decay.
5. On a wheels-raised stand, use a current-limited 6 V source and low duty.
   Establish motor polarity and encoder phase. Do not run a prolonged stall.

## Evidence matrix

| Case | Record | Required result |
|---|---|---|
| Socket fit | gap, engagement, photos | no interference or forced seating |
| Unpowered continuity | full connector pin map | exact net map; no host/base ground tie |
| Assembly | solder and inspection record | reflow SMD first, hand-solder through-hole parts afterward; inspect joints and labels |
| Probe access | pad identities and photos | all ten top pads reachable without bridging adjacent nets |
| Partial power | Pi-only, Shrike-only, sensor-5-V-only | no unacceptable backfeed |
| Fault observation | force/observe DRV fault | both F_GPIO7 and RP GPIO28 see their buffered active-low fault |
| Logic stop | open/break J5 loop | `nSLEEP` stop level and gated inputs low |
| Independent stop | open external stop path | J7 motor 6 V removed without software participation |
| Sensors | distance, no/stuck echo; IMU/INT | measured behavior and stated limit |
| Encoder | low-energy rotation both directions | measured phase/order; CPR recorded if derived |
| Wheels raised | low-duty start/stop/reverse | direction, current, sag, temperature, fault state |
| Floor run | supervised run after prior passes | stop distance and stable wiring |

For each run retain time, carrier/harness revision, available Pi/Shrike/FPGA
software identifiers, source voltage, current limit, instrument, acceptance
limit, raw captures, measurement, and verdict. A CAD check or software build
cannot substitute for physical records.

## Release state

Fabrication, physical test, and motion release remain **false** until real
evidence is attached. No Pi, RP2040, or FPGA firmware is claimed implemented
or flashed by this hardware repository.

## Controller and measurement acceptance

Use the independent [bench fixture](bench.md) to prepare wire vectors and check
logic captures. Offline fixture success is not a physical acceptance result.

Motion remains blocked until the existing AxiomOS host, RP2040 adapter and FPGA
bitstream have a validated timing manifest, atomic command/watchdog/e-stop
handling, explicit rearm after stop or driver fault, and real Pi RP1-UART support.
Record expiry/watchdog/stop bounds before testing; use the tighter specified
bound as the limit, not the best observed trace. After `nSLEEP` rises, allow
at least the DRV8833 datasheet wake-up time (1 ms) before permitting PWM.

Exercise expired, malformed, repeated and out-of-order commands, UART unplug,
host reset/stall, RP reset, FPGA unconfigured/reset, and stop release without
rearm. Each must preserve or enter the specified coast/off state. Capture all
four DRV inputs, nSLEEP, motor current and the independent relay response.
With motor power absent, deliberately drive each observation GPIO incorrectly
through its 1 kΩ resistor and confirm it cannot raise hardware nSLEEP or mask
the other controller's stop/fault signal. Restore inputs before motion tests.

Calibrate left/right wheel circumference and quadrature counts per output
revolution; do not infer x4 counts from the seller's “11 pulses” wording. Record
IMU axis orientation/bias and HC-SR04 timeout/no-echo behavior. Start below
0.2 m/s on an indoor level floor and keep total rover mass at or below 2 kg;
these are design targets to qualify, not measured capabilities.

Use a current-limited bench supply first. Measure nominal 1 A current chopping,
start current, both-channel driver/sense-resistor temperatures, VM ripple and
stop/reverse overshoot before choosing a commercial motor pack/regulator.
C8 470 µF, 16 V and D1 SMBJ6.0A still need exact manufacturer/order-code
selection before fabrication. Verify the Rev B.1 sense and capacitor placement
targets in CAD; bench captures are still required for electrical acceptance.
C5's effective ceramic capacitance at bias, C8's energy/rail-decay behavior,
and D1's pulse temperature need qualification. Keep every rail within its part's
recommended limits, not merely absolute maximum ratings. A nominally 6 V
battery label does not establish a regulated 6 V output.

For partial-power cases, compare measured leakage, rail rise and receiver
levels to the selected parts' datasheet limits and record the actual limits in
the test log. For Pi, also capture USB-C voltage/current under sustained compute
load. Check the stop button, fuse, coil clamp and K1 normally-open contact with
host and controller absent: software must not be necessary to remove motor power.

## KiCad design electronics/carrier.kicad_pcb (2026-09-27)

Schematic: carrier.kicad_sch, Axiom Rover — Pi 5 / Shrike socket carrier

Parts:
C1, C2, C3, C4, C9: 100nF 16V X7R; C_0805_2012Metric
C5: 10uF 16V X7R; C_1206_3216Metric
C6: 10nF 25V X7R; C_0805_2012Metric
C7: 2.2uF 16V X7R; C_0805_2012Metric
C8: 470uF 16V; CP_Radial_D8.0mm_P3.50mm
D1: SMBJ6.0A; D_SMB
J1: ESQ-120-24-G-D_PI5_BOTTOM; Pi5_Socket_2x20
J2: SHRIKE_J2_SSW-119-01-G-S; SSW-119-01-G-S
J3: HC_SR04_VCC_TRIG_ECHO_GND; JST_XH_B4B-XH-A_1x04_P2.50mm_Vertical
J4: SHRIKE_J4_SSW-119-01-G-S; SSW-119-01-G-S
J5: ESTOP_LOGIC_NC; JST_XH_B2B-XH-A_1x02_P2.50mm_Vertical
J6: BASE_SENSOR_5V_IN; JST_XH_B2B-XH-A_1x02_P2.50mm_Vertical
J7: 6V_AFTER_FUSE_AND_STOP_RELAY; JST_VH_B2P-VH_1x02_P3.96mm_Vertical
J8: LEFT_MOTOR; JST_VH_B2P-VH_1x02_P3.96mm_Vertical
J9: RIGHT_MOTOR; JST_VH_B2P-VH_1x02_P3.96mm_Vertical
J10: ENCODER_LEFT_3V3; JST_XH_B4B-XH-A_1x04_P2.50mm_Vertical
J11: ENCODER_RIGHT_3V3; JST_XH_B4B-XH-A_1x04_P2.50mm_Vertical
J12: ALTERNATE_HOST_UART; JST_XH_B4B-XH-A_1x04_P2.50mm_Vertical
J13: IMU_3V3_I2C_INT; JST_XH_B5B-XH-A_1x05_P2.50mm_Vertical
R1, R16, R17, R18, R19: 1k 1%; R_0805_2012Metric
R2: 2.2k 1%; R_0805_2012Metric
R3: 3.3k 1%; R_0805_2012Metric
R4, R5, R6, R9, R10, R11, R12, R13: 10k 1%; R_0805_2012Metric
R7, R8: 0.20R 1W CSRT1206FTR200; R_1206_3216Metric
R14, R15: 4.7k 1%; R_0805_2012Metric
TP1: HOST_3V3; TestPoint_Pad_D1.5mm
TP2: H_GND; TestPoint_Pad_D1.5mm
TP3: BASE_3V3; TestPoint_Pad_D1.5mm
TP4: BASE_5V; TestPoint_Pad_D1.5mm
TP5: MOTOR_6V; TestPoint_Pad_D1.5mm
TP6: BASE_GND; TestPoint_Pad_D1.5mm
TP7: ESTOP_N; TestPoint_Pad_D1.5mm
TP8: DRV_FAULT_N; TestPoint_Pad_D1.5mm
TP9: SENSE_L; TestPoint_Pad_D1.5mm
TP10: SENSE_R; TestPoint_Pad_D1.5mm
U1: ISO7721DR; SOIC-8_3.9x4.9mm_P1.27mm
U2: SN74LVC1G17DBVR; SOT-23-5
U3: DRV8833PWPR; HTSSOP-16-1EP_4.4x5mm_P0.65mm_EP3.4x5mm_Mask2.46x2.31mm_The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
U4: SN74LVC08ADR; SOIC-14_3.9x8.7mm_P1.27mm
U5: SN74LVC125ADR; SOIC-14_3.9x8.7mm_P1.27mm

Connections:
/BASE_3V3: C2.1, C3.1, C4.1, C9.1, J2.2, J4.2, J5.1, J10.2, J11.2, J13.2, R9.2, R14.2, R15.2, TP3.1, U1.8 (VCC2), U2.5 (VCC), U4.14 (VCC), U5.14 (VCC)
/BASE_5V: J3.1, J6.1, TP4.1
/BASE_GND: C2.2, C3.2, C4.2, C5.2, C7.2, C8.2, C9.2, D1.2 (A), J2.8, J2.13, J3.4, J4.7, J4.13, J4.19, J6.2, J7.2, J10.1, J11.1, J13.1, R3.2, R4.2, R5.2, R6.2, R7.2, R8.2, R10.2, R11.2, R12.2, R13.2, TP6.1, U1.5 (GND2), U2.3 (GND), U3.13 (GND), U3.17 (EP), U4.7 (GND), U5.1 (1OE_N), U5.4 (2OE_N), U5.7 (GND), U5.10 (3OE_N), U5.13 (4OE_N)
/DRV_AIN1: U3.16 (AIN1), U4.3 (1Y)
/DRV_AIN2: U3.15 (AIN2), U4.6 (2Y)
/DRV_BIN1: U3.9 (BIN1), U4.8 (3Y)
/DRV_BIN2: U3.10 (BIN2), U4.11 (4Y)
/DRV_FAULT_N: R9.1, TP8.1, U3.8 (nFAULT), U5.9 (3A), U5.12 (4A)
/DRV_VCP: C6.1, U3.11 (VCP)
/DRV_VINT: C7.1, U3.14 (VINT)
/ECHO_DIV: R2.2, R3.1, U2.2 (A)
/ENC_L_A: J4.14, J10.3
/ENC_L_B: J4.12, J10.4
/ENC_R_A: J4.11, J11.3
/ENC_R_B: J4.10, J11.4
/ESTOP_FPGA: J2.16, R17.2
/ESTOP_FPGA_DRIVE: R17.1, U5.6 (2Y)
/ESTOP_N: J5.2, R4.1, TP7.1, U3.1 (nSLEEP), U5.2 (1A), U5.5 (2A)
/ESTOP_RP: J2.3, R16.2
/ESTOP_RP_DRIVE: R16.1, U5.3 (1Y)
/FAULT_FPGA_DRIVE: R19.1, U5.11 (4Y)
/FAULT_FPGA_N: J2.19, R19.2
/FAULT_RP_DRIVE: R18.1, U5.8 (3Y)
/FAULT_RP_N: J4.4, R18.2
/FPGA_PWM_L: J2.17, R5.1, U4.2 (1B), U4.5 (2B)
/FPGA_PWM_R: J2.18, R6.1, U4.10 (3B), U4.13 (4B)
/HOST_3V3: C1.1, J1.1, J1.17, J12.1, TP1.1, U1.1 (VCC1)
/H_GND: C1.2, J1.6, J1.9, J1.14, J1.20, J1.25, J1.30, J1.34, J1.39, J12.2, TP2.1, U1.4 (GND1)
/H_RX: J1.10, J12.4, U1.2 (OUTA)
/H_TX: J1.8, J12.3, U1.3 (INB)
/IMU_INT: J4.3, J13.5
/IMU_SCL: J4.5, J13.4, R15.1
/IMU_SDA: J4.6, J13.3, R14.1
/L_IN1: J2.4, R10.1, U4.1 (1A)
/L_IN2: J2.5, R11.1, U4.4 (2A)
/MOTOR_6V: C5.1, C6.2, C8.1, D1.1 (K), J7.1, TP5.1, U3.12 (VM)
/MOTOR_L_N: J8.2, U3.4 (AOUT2)
/MOTOR_L_P: J8.1, U3.2 (AOUT1)
/MOTOR_R_N: J9.2, U3.5 (BOUT2)
/MOTOR_R_P: J9.1, U3.7 (BOUT1)
/RP_UART_RX: J4.17, U1.6 (OUTB)
/RP_UART_TX: J4.18, U1.7 (INA)
/R_IN3: J2.6, R12.1, U4.9 (3A)
/R_IN4: J2.7, R13.1, U4.12 (4A)
/SENSE_L: R7.1, TP9.1, U3.3 (AISEN)
/SENSE_R: R8.1, TP10.1, U3.6 (BISEN)
/SENSOR_TRIG: J3.2, R1.2
/US_ECHO_3V: J2.10, U2.4 (Y)
/US_ECHO_5V: J3.3, R2.1
/US_TRIG: J2.9, R1.1

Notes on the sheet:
REV B.1: Pi 5 bottom socket + Shrike R0.4 top sockets; no host/base ground tie
J7: REGULATED 6 V AFTER EXTERNAL FUSE + INDEPENDENT STOP RELAY. 1 A nominal per motor.
FPGA PWM gates direction inputs through U4. nSLEEP is STOP level, never PWM.
Shrike USB-C is sole 5 V power entry. J1 pins 2/4 and J2/J4 pin 1 stay disconnected.
REVIEW ONLY: physical fit, current limit, cooling and firmware timing require bench evidence.

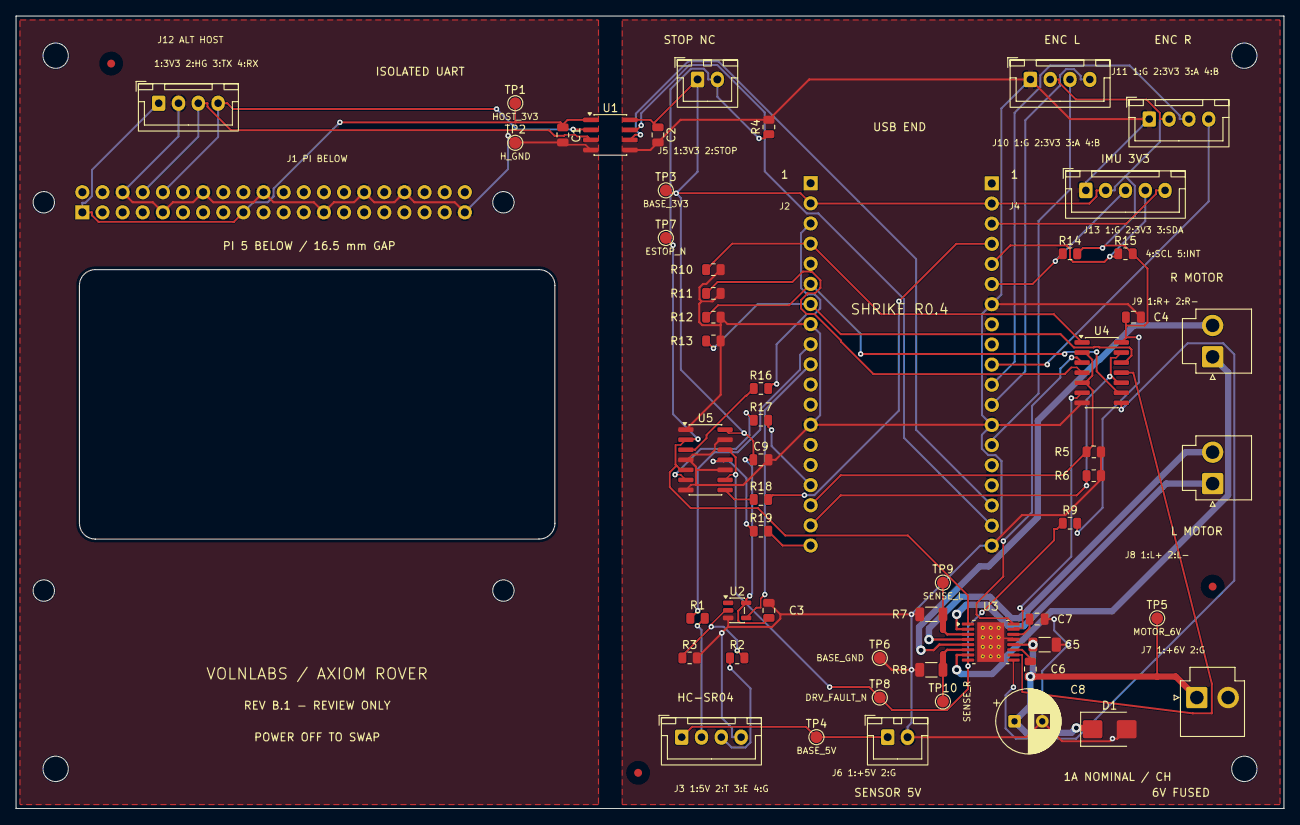
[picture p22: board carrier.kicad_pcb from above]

Board: 2 copper layers, 160.0 x 100.0 mm, 68 parts (1 on the bottom side), 50 nets.

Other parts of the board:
FID1, FID2, FID3: Fiducial; Fiducial_1mm_Mask3mm
H1, H2, H3, H4: M3 NPTH; MountingHole_3.2mm_M3
H5, H6, H7, H8: M2.5 NPTH; MountingHole_2.7mm_M2.5

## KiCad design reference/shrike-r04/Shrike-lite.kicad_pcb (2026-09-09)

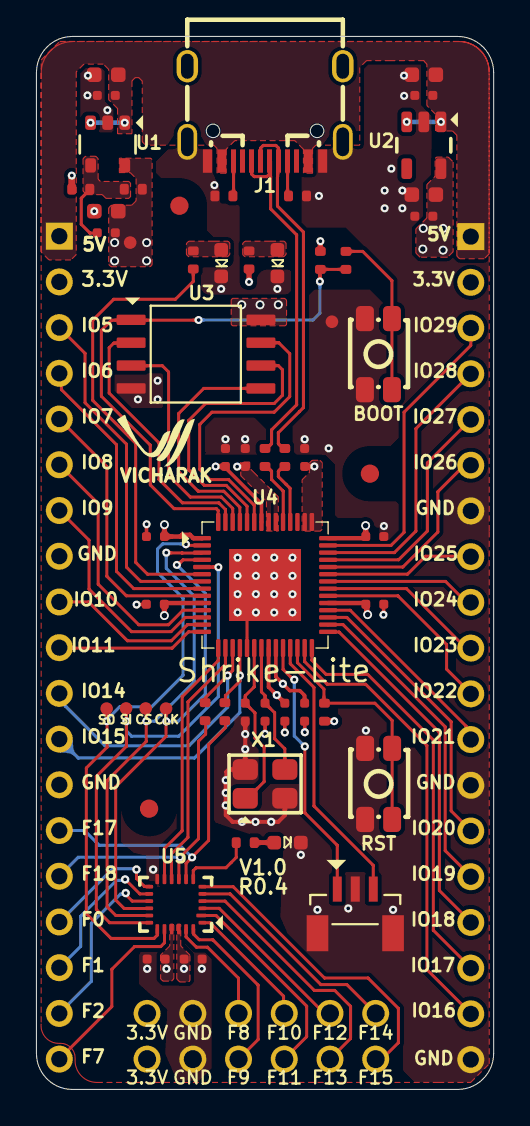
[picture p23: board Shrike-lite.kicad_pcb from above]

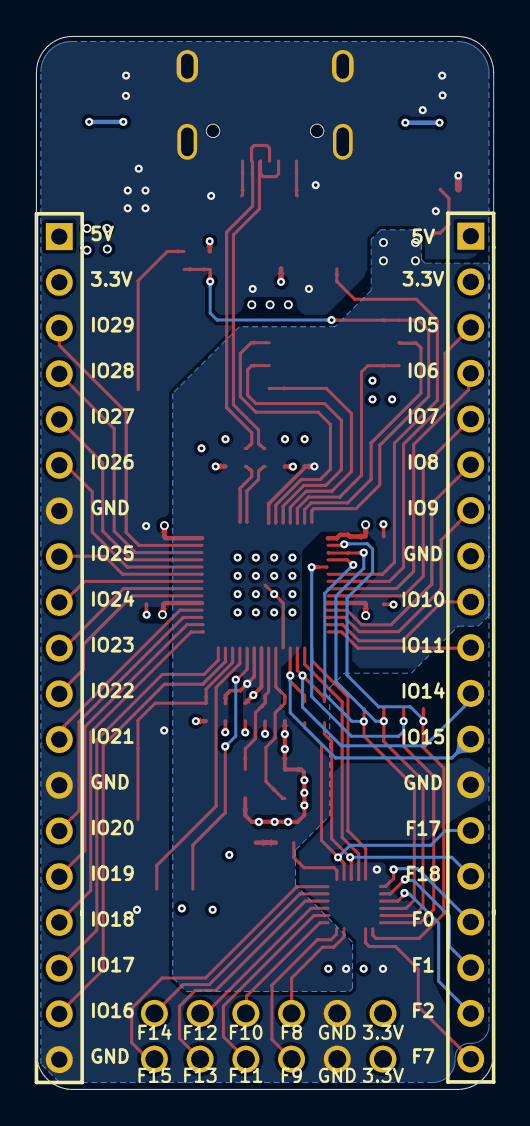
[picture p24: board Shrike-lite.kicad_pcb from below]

Board: 4 copper layers, 25.4 x 58.5 mm, 57 parts (2 on the bottom side), 71 nets.

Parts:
2: TP
C1, C3, C5, C8: 100nF 10V; CAPC0603
C2, C4, C6, C7, C9, C10, C11, C12, C13, C14, C15, C16, C17, C18, C19, C20, C21: CAP_0402
CLK: TP
CS: TP
D1: LED1; LED_0603
D2, D3: LED_0603
GND1: TP
J1: TYPE-C
J2, J4: Header 19X1_2.54MM; HEADER_19X1_2.54
J3: DNP; 6X2 HEADER 2.54MM
J5: XUNPU WAFER-SH1.0-3PLB
R1: RES_0402_5; RESC0402
R2, R3, R4, R5, R6, R7, R8, R9, R10, R11, R12, R13, R14: RESC0402
SI: TP
SO: TP
SW1, SW2: SW PUSHBUTTON; SW_MICRO PUSH BUTTON 4 PAD
U1: SOT23-5
U2: SOT25-5
U3: SOIC-8_208MIL
U4: RP2040; QFN-56 7X7
U5: QFN24 3X3
X1: CRYSTAL_3225

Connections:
1.1V: 2.1, C7.2, C8.2, C11.1, C12.1, C20.1, R4.1, U1.5, U4.23, U4.50, U5.22
3.3V: C3.2, C4.2, C13.1, C14.1, C15.1, C16.1, C17.1, C18.1, C19.1, C21.1, J2.2, J3.1, J3.2, J4.2, R1.1, R9.1, R10.2, U2.5, U3.8, U4.1, U4.10, U4.22, U4.33, U4.42, U4.43, U4.44, U4.48, U4.49, U5.21
BOOT: R11.2, SW2.1, SW2.2
CS0: R9.2, R11.1, U3.1, U4.56
CS1: CS.1, U4.3, U5.17
EN: U4.16, U5.10
F_GPIO0: J2.16, U5.13
F_GPIO1: J2.17, U5.14
F_GPIO2: J2.18, U5.15
F_GPIO7: J2.19, U5.20
F_GPIO8: J3.6, U5.23
F_GPIO9: J3.5, U5.24
F_GPIO10: J3.8, U5.1
F_GPIO11: J3.7, U5.2
F_GPIO12: J3.10, U5.3
F_GPIO13: J3.9, U5.4
F_GPIO14: J3.12, U5.5
F_GPIO15: J3.11, U5.6
F_GPIO16: R6.1, U5.7
F_GPIO17: J2.14, R8.2, U5.8
F_GPIO18: J2.15, R7.2, U5.9
F_SPI_CLK: CLK.1, U4.4, U5.16
F_SPI_SI: SI.1, U4.5, U5.18
F_SPI_SO: SO.1, U4.2, U5.19
GND: C1.1, C2.1, C3.1, C4.1, C5.1, C6.1, C8.1, C9.2, C10.2, C11.2, C12.2, C13.2, C14.2, C15.2, C16.2, C17.2, C18.2, C19.2, C20.2, C21.2, D1.K, D2.K, D3.K, GND1.1, J1.A1, J1.A12, J1.S1, J1.S2, J1.S3, J1.S4, J2.8, J2.13, J3.3, J3.4, J4.7, J4.13, J4.19, J5.2, J5.4, J5.5, R2.2, R3.2, R5.2, SW1.3, SW1.4, SW2.3, SW2.4, U1.2, U2.2, U3.4, U4.19, U4.57, U5.12, X1.2, X1.4
GPIO4: R14.1, U4.6
GPIO5: J2.3, U4.7
GPIO6: J2.4, U4.8
GPIO7: J2.5, U4.9
GPIO8: J2.6, U4.11
GPIO9: J2.7, U4.12
GPIO10: J2.9, U4.13
GPIO11: J2.10, U4.14
GPIO14: J2.11, R7.1, U4.17
GPIO15: J2.12, R8.1, U4.18
GPIO16: J4.18, U4.27
GPIO17: J4.17, U4.28
GPIO18: J4.16, U4.29
GPIO19: J4.15, U4.30
GPIO20: J4.14, U4.31
GPIO21: J4.12, U4.32
GPIO22: J4.11, U4.34
GPIO23: J4.10, U4.35
GPIO24: J4.9, U4.36
GPIO25: J4.8, U4.37
GPIO26: J4.6, U4.38
GPIO27: J4.5, U4.39
GPIO28: J4.4, U4.40
GPIO29: J4.3, U4.41
HOLD: U3.7, U4.51
NetC7_1: C7.1, R4.2, R5.1, U1.4
NetD1_A: D1.A, R1.2
NetD2_A: D2.A, R6.2
NetD3_A: D3.A, R14.2
NetJ1_A5: J1.A5, R3.1
NetJ1_B5: J1.B5, R2.1
PWR: U4.15, U5.11
RUN: R10.1, SW1.1, SW1.2, U4.26
SPI_CLK: U3.6, U4.52
SPI_SI: U3.5, U4.53
SPI_SO: U3.2, U4.55
SWCLK: J5.1, U4.24
SWD: J5.3, U4.25
USB_N: J1.A7, J1.B7, R12.1
USB_P: J1.A6, J1.B6, R13.1
USBx_N: R12.2, U4.46
USBx_P: R13.2, U4.47
VUSB: C1.2, C2.2, C5.2, C6.2, J1.A4, J1.A9, J2.1, J4.1, U1.1, U1.3, U2.1, U2.3
WP: U3.3, U4.54
XIN: C9.1, U4.20, X1.1
XOUT: C10.1, U4.21, X1.3

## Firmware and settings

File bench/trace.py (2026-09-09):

#!/usr/bin/env python3
"""Validate a RevB bench logic capture against its predeclared cases."""

import argparse
import csv
import hashlib
import io
import json
import math
import os
from pathlib import Path


SIGNALS = (
    "estop_n", "fault_n", "pwm_l", "pwm_r", "l_in1", "l_in2",
    "r_in3", "r_in4", "drv_ain1", "drv_ain2", "drv_bin1",
    "drv_bin2", "nsleep",
)
STARTUP_LOW = ("pwm_l", "pwm_r", "l_in1", "l_in2", "r_in3", "r_in4", "drv_ain1", "drv_ain2", "drv_bin1", "drv_bin2")
OFF_SIGNALS = ("pwm_l", "pwm_r", "drv_ain1", "drv_ain2", "drv_bin1", "drv_bin2")


def _finite_number(value):
    return isinstance(value, (int, float)) and not isinstance(value, bool) and math.isfinite(value)


def _failure(source_hash, evidence_kind, errors, checked=()):
    limitation = (
        "Synthetic evidence does not establish physical hardware behavior."
        if evidence_kind == "synthetic"
        else "Digital samples cannot establish sub-sample analog timing or motor behavior."
    )
    return {
        "passed": False,
        "source_sha256": source_hash,
        "checked_case_ids": list(checked),
        "evidence_kind": evidence_kind,
        "limitation": limitation + (
            " Event times are externally annotated and need raw UART/SPI/reset capture corroboration."
            " This report does not authenticate metadata, identify the stimulus or ack owner, or measure requested PWM duty."
        ),
        "errors": errors,
    }


def _load_manifest(data):
    value = json.loads(data.decode("utf-8"))
    if not isinstance(value, dict):
        raise ValueError("manifest must be a JSON object")
    evidence = value.get("evidence")
    limits = value.get("limits")
    startup = value.get("startup")
    cases = value.get("off_intervals")
    if value.get("schema_version") != 1:
        raise ValueError("schema_version must be 1")
    if not isinstance(evidence, dict) or evidence.get("kind") not in ("physical", "synthetic"):
        raise ValueError("evidence.kind must be physical or synthetic")
    required = ("hardware_revision", "software_ids", "instruments", "power_state")
    if any(not evidence.get(name) for name in required):
        raise ValueError("evidence metadata is incomplete")
    if evidence.get("limits_declared_before_evaluation") is not True:
        raise ValueError("limits must be declared before evaluation")
    if not isinstance(evidence["software_ids"], dict) or not isinstance(evidence["instruments"], list):
        raise ValueError("software_ids must be an object and instruments a list")
    for instrument in evidence["instruments"]:
        if not isinstance(instrument, dict) or any(
            name not in instrument for name in ("name", "calibration", "time_resolution_us", "timing_uncertainty_us")
        ):
            raise ValueError("each instrument needs name, calibration, time_resolution_us, and timing_uncertainty_us")
        if any(not isinstance(instrument[name], str) or not instrument[name] for name in ("name", "calibration")):
            raise ValueError("instrument name and calibration must be nonempty strings")
        for field in ("time_resolution_us", "timing_uncertainty_us"):
            number = instrument[field]
            if not _finite_number(number) or number < 0:
                raise ValueError(f"instrument {field} must be finite and nonnegative")
        if instrument["time_resolution_us"] == 0:
            raise ValueError("instrument time_resolution_us must be positive")
    if not isinstance(limits, dict):
        raise ValueError("limits must be an object")
    for name in ("digital_tolerance_us", "min_direction_mask_us", "min_wakeup_us", "max_sample_gap_us"):
        number = limits.get(name)
        if not _finite_number(number) or number < 0:
            raise ValueError(f"limits.{name} must be finite and nonnegative")
    if limits["max_sample_gap_us"] == 0:
        raise ValueError("limits.max_sample_gap_us must be positive")
    if evidence["power_state"] != "motor_disconnected":
        raise ValueError("phase1 power_state must be motor_disconnected")
    if evidence["kind"] == "physical":
        ids = evidence["software_ids"]
        exact = {"host_commit", "rp2040_commit", "rp2040_sha256", "fpga_commit", "fpga_sha256", "timing_manifest_sha256"}
        if set(ids) != exact or any(not isinstance(ids[name], str) or not ids[name] for name in exact):
            raise ValueError("physical evidence requires the exact nonempty software_ids fields")
        for name in ("rp2040_sha256", "fpga_sha256", "timing_manifest_sha256"):
            if len(ids[name]) != 64 or any(char not in "0123456789abcdefABCDEF" for char in ids[name]):
                raise ValueError(f"physical evidence {name} must be a 64-digit hex hash")
        if limits["min_wakeup_us"] < 1000:
            raise ValueError("physical evidence min_wakeup_us must be at least 1000")
    if not isinstance(startup, dict) or not _finite_number(startup.get("observe_until_us")) or startup["observe_until_us"] < 0:
        raise ValueError("startup.observe_until_us is required")
    if not isinstance(cases, list):
        raise ValueError("off_intervals must be a list")
    ids = set()
    for case in cases:
        expected_fields = {"id", "event_us", "stop_deadline_us", "observe_until_us", "max_pre_event_drive_gap_us"}
        if not isinstance(case, dict) or set(case) != expected_fields:
            raise ValueError("each off interval needs exactly id, event_us, stop_deadline_us, observe_until_us, max_pre_event_drive_gap_us")
        case_id = case["id"]
        times = [case[name] for name in ("event_us", "stop_deadline_us", "observe_until_us")]
        if not isinstance(case_id, str) or not case_id or case_id in ids:
            raise ValueError("case IDs must be unique nonempty strings")
        if any(not _finite_number(t) for t in times) or not times[0] <= times[1] <= times[2]:
            raise ValueError(f"case {case_id}: require finite event <= stop deadline <= observe until")
        if not _finite_number(case["max_pre_event_drive_gap_us"]) or case["max_pre_event_drive_gap_us"] <= 0:
            raise ValueError(f"case {case_id}: max_pre_event_drive_gap_us must be finite and positive")
        ids.add(case_id)
    return value


def _load_rows(data):
    with io.StringIO(data.decode("utf-8"), newline="") as stream:
        reader = csv.DictReader(stream)
        expected = {"time_us", *SIGNALS}
        if reader.fieldnames is None or set(reader.fieldnames) != expected or len(reader.fieldnames) != len(expected):
            raise ValueError("CSV columns must be exactly time_us and the required signals")
        rows = []
        previous = None
        for line, raw in enumerate(reader, 2):
            if None in raw or any(value is None for value in raw.values()):
                raise ValueError(f"line {line}: row does not match the CSV header")
            try:
                when = float(raw["time_us"])
            except (TypeError, ValueError):
                raise ValueError(f"line {line}: invalid time_us") from None
            if not math.isfinite(when) or previous is not None and when <= previous:
                raise ValueError(f"line {line}: time_us must be finite and strictly increasing")
            row = {"time_us": when}
            for signal in SIGNALS:
                if raw[signal] not in ("0", "1"):
                    raise ValueError(f"line {line}: {signal} must be exactly 0 or 1")
                row[signal] = int(raw[signal])
            rows.append(row)
            previous = when
    if not rows:
        raise ValueError("capture has no samples")
    return rows


def _edge_times(rows, expected):
    values = [expected(row) for row in rows]
    return [rows[i]["time_us"] for i in range(1, len(rows)) if values[i] != values[i - 1]]


def _check_follow(rows, output, expected, tolerance, errors):
    edges = _edge_times(rows, expected)
    for row in rows:
        if row[output] != expected(row) and not any(0 <= row["time_us"] - edge <= tolerance for edge in edges):
            errors.append(f"{output} mismatch at {row['time_us']} us outside {tolerance} us tolerance")


def evaluate(manifest_path, csv_path):
    source_hash = manifest_hash = ""
    evidence_kind = "unknown"
    try:
        source = Path(csv_path).read_bytes()
        manifest_source = Path(manifest_path).read_bytes()
        source_hash = hashlib.sha256(source).hexdigest()
        manifest_hash = hashlib.sha256(manifest_source).hexdigest()
        manifest = _load_manifest(manifest_source)
        evidence_kind = manifest["evidence"]["kind"]
        rows = _load_rows(source)
    except (OSError, UnicodeError, json.JSONDecodeError, ValueError) as error:
        report = _failure(source_hash, evidence_kind, [str(error)])
        report["manifest_sha256"] = manifest_hash
        report["checker_sha256"] = hashlib.sha256(Path(__file__).read_bytes()).hexdigest()
        return report

    errors = []
    physical_margin = 0
    if evidence_kind == "physical":
        physical_margin = 2 * max(
            item["time_resolution_us"] + item["timing_uncertainty_us"]
            for item in manifest["evidence"]["instruments"]
        )
    tolerance = manifest["limits"]["digital_tolerance_us"]
    maximum_gap = manifest["limits"]["max_sample_gap_us"]
    for previous, current in zip(rows, rows[1:]):
        if current["time_us"] - previous["time_us"] > maximum_gap:
            errors.append(f"sample gap ending at {current['time_us']} us exceeds {maximum_gap} us")
    _check_follow(rows, "nsleep", lambda row: row["estop_n"], tolerance, errors)
    for output, direction, pwm in (
        ("drv_ain1", "l_in1", "pwm_l"), ("drv_ain2", "l_in2", "pwm_l"),
        ("drv_bin1", "r_in3", "pwm_r"), ("drv_bin2", "r_in4", "pwm_r"),
    ):
        _check_follow(rows, output, lambda row, d=direction, p=pwm: row[d] & row[p], tolerance, errors)

    minimum = manifest["limits"]["min_direction_mask_us"] + physical_margin
    for directions, pwm in (("l_in1 l_in2".split(), "pwm_l"), ("r_in3 r_in4".split(), "pwm_r")):
        low_since = rows[0]["time_us"] if not rows[0][pwm] else None
        last_direction_change = None
        for index, row in enumerate(rows):
            if index and rows[index - 1][pwm] and not row[pwm]:
                low_since = row["time_us"]
            if index and any(row[name] != rows[index - 1][name] for name in directions):
                last_direction_change = row["time_us"]
                if rows[index - 1][pwm] or row[pwm]:
                    errors.append(f"{pwm} was not low on both samples around direction change at {row['time_us']} us")
                elif low_since is None or row["time_us"] - low_since < minimum:
                    errors.append(f"{pwm} mask before direction change at {row['time_us']} us was shorter than {minimum} us")
            if index and not rows[index - 1][pwm] and row[pwm]:
                if last_direction_change is not None and row["time_us"] - last_direction_change < minimum:
                    errors.append(f"direction did not settle for {minimum} us before {pwm} rose at {row['time_us']} us")
                low_since = None

    awake_since = rows[0]["time_us"] if rows[0]["nsleep"] else None
    for index, row in enumerate(rows):
        if index and rows[index - 1]["nsleep"] and not row["nsleep"]:
            awake_since = None
        if index and not rows[index - 1]["nsleep"] and row["nsleep"]:
            awake_since = row["time_us"]
            if row["pwm_l"] or row["pwm_r"]:
                errors.append(f"nSLEEP rose while PWM was high at {row['time_us']} us")
        for pwm in ("pwm_l", "pwm_r"):
            if index and not rows[index - 1][pwm] and row[pwm]:
                required = manifest["limits"]["min_wakeup_us"] + physical_margin
                if awake_since is None or row["time_us"] - awake_since < required:
                    errors.append(f"{pwm} rose before the declared nSLEEP wakeup interval at {row['time_us']} us")

    startup_end = manifest["startup"]["observe_until_us"]
    if rows[0]["time_us"] > 0 or rows[-1]["time_us"] < startup_end:
        errors.append("capture does not cover the startup window from 0 us")
    elif any(row[name] for row in rows if row["time_us"] <= startup_end for name in STARTUP_LOW):
        errors.append("startup outputs are not default-low")

    checked = []
    case_reports = []
    for case in manifest["off_intervals"]:
        case_id = case["id"]
        checked.append(case_id)
        event, deadline, hold_end = case["event_us"], case["stop_deadline_us"], case["observe_until_us"]
        if rows[0]["time_us"] > event or rows[-1]["time_us"] < hold_end + physical_margin:
            errors.append(f"case {case_id}: capture does not cover event, deadline, and hold window")
            continue
        before = [row for row in rows if row["time_us"] < event]
        latest = before[-1] if before else None
        earliest_drive = event - case["max_pre_event_drive_gap_us"]
        recent = []
        for row in before:
            if row["time_us"] < earliest_drive:
                continue
            if row["pwm_l"] and (row["drv_ain1"] or row["drv_ain2"]):
                recent.append((row["time_us"], ("l_in1", "l_in2")))
            if row["pwm_r"] and (row["drv_bin1"] or row["drv_bin2"]):
                recent.append((row["time_us"], ("r_in3", "r_in4")))
        observed_gap = event - max((item[0] for item in recent), default=event)
        if not recent:
            errors.append(f"case {case_id}: no recent drive-high sample before event")
            observed_gap = None
        elif latest is None or not latest["nsleep"] or not any(any(latest[name] for name in directions) for _, directions in recent):
            errors.append(f"case {case_id}: pre-event direction or nSLEEP was not enabled for the driven channel")
        case_reports.append({"id": case_id, "observed_pre_event_drive_gap_us": observed_gap})
        deadline_candidates = [i for i, row in enumerate(rows) if row["time_us"] <= deadline - physical_margin]
        if not deadline_candidates:
            errors.append(f"case {case_id}: no sample proves stop before deadline with timing margin")
            continue
        deadline_index = max(deadline_candidates)
        hold_index = min(i for i, row in enumerate(rows) if row["time_us"] >= hold_end + physical_margin)
        if any(rows[i][name] for i in range(deadline_index, hold_index + 1) for name in OFF_SIGNALS):
            errors.append(f"case {case_id}: gates or driver inputs were not off by deadline and held off")

    report = _failure(source_hash, evidence_kind, errors, checked)
    report["passed"] = not errors
    report["manifest_sha256"] = manifest_hash
    report["checker_sha256"] = hashlib.sha256(Path(__file__).read_bytes()).hexdigest()
    report["declared_limits"] = manifest["limits"]
    report["hardware_revision"] = manifest["evidence"]["hardware_revision"]
    report["power_state"] = manifest["evidence"]["power_state"]
    report["physical_timing_margin_us"] = physical_margin
    report["startup_checked"] = True
    report["cases"] = case_reports
    return report


def main():
    parser = argparse.ArgumentParser(description=__doc__)
    parser.add_argument("manifest", type=Path)
    parser.add_argument("csv", type=Path)
    parser.add_argument("--output", type=Path, required=True)
    args = parser.parse_args()
    aliases_input = args.output.exists() and any(os.path.samefile(args.output, source) for source in (args.manifest, args.csv))
    if args.output.resolve() in (args.manifest.resolve(), args.csv.resolve()) or aliases_input:
        parser.error("--output must differ from both input paths")
    try:
        report = evaluate(args.manifest, args.csv)
    except OSError as error:
        report = _failure("", "unknown", [str(error)])
    args.output.write_text(json.dumps(report, indent=2, sort_keys=True) + "\n", encoding="utf-8")
    return 0 if report["passed"] else 1


if __name__ == "__main__":
    raise SystemExit(main())

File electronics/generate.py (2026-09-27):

#!/usr/bin/env python3
"""Generate review-revision carrier source with KiCad's bundled pcbnew Python.
Re-running replaces CAD edits: use generated KiCad files directly for manual revision.
"""
import argparse, csv, json, os, uuid, shutil, math, re
from pathlib import Path
import pcbnew as k

ROOT = Path(__file__).resolve().parent
UID = lambda s: str(uuid.uuid5(uuid.NAMESPACE_URL, 'volnlabs/axiom-rover/carrier/'+s))
SHEET = UID('sheet')
def xh(n): return f'Connector_JST:JST_XH_B{n}B-XH-A_1x{n:02d}_P2.50mm_Vertical'
R = 'Resistor_SMD:R_0805_2012Metric'
C = 'Capacitor_SMD:C_0805_2012Metric'
# ref, value, footprint, physical-pad-ordered nets, PCB x/y/angle, schematic x/y
# J1 is fitted BELOW the PCB; its pad numbers are stated in top-board coordinates.
PI_NETS=[None]*40
for pin,net in {1:'HOST_3V3',17:'HOST_3V3',6:'H_GND',9:'H_GND',14:'H_GND',20:'H_GND',25:'H_GND',30:'H_GND',34:'H_GND',39:'H_GND',8:'H_TX',10:'H_RX'}.items(): PI_NETS[pin-1]=net
SENSOR_FP=lambda n: xh(n)
POWER_FP='Connector_JST:JST_VH_B2P-VH_1x02_P3.96mm_Vertical'
DRV_FP='Package_SO:HTSSOP-16-1EP_4.4x5mm_P0.65mm_EP3.4x5mm_Mask2.46x2.31mm_ThermalVias'
PARTS=[
('J1','ESQ-120-24-G-D_PI5_BOTTOM','Rover:Pi5_Socket_2x20',PI_NETS,(0,20,0),(70,100)),
('J2','SHRIKE_J2_SSW-119-01-G-S','Rover:SSW-119-01-G-S',[None,'BASE_3V3','ESTOP_RP','L_IN1','L_IN2','R_IN3','R_IN4','BASE_GND','US_TRIG','US_ECHO_3V',None,None,'BASE_GND',None,None,'ESTOP_FPGA','FPGA_PWM_L','FPGA_PWM_R','FAULT_FPGA_N'],(100.27,21.0958,0),(245,100)),
('J4','SHRIKE_J4_SSW-119-01-G-S','Rover:SSW-119-01-G-S',[None,'BASE_3V3','IMU_INT','FAULT_RP_N','IMU_SCL','IMU_SDA','BASE_GND',None,None,'ENC_R_B','ENC_R_A','ENC_L_B','BASE_GND','ENC_L_A',None,None,'RP_UART_RX','RP_UART_TX','BASE_GND'],(123.13,21.121,0),(420,100)),
('U3','DRV8833PWPR',DRV_FP,['ESTOP_N','MOTOR_L_P','SENSE_L','MOTOR_L_N','MOTOR_R_N','SENSE_R','MOTOR_R_P','DRV_FAULT_N','DRV_BIN1','DRV_BIN2','DRV_VCP','MOTOR_6V','BASE_GND','DRV_VINT','DRV_AIN2','DRV_AIN1','BASE_GND'],(123,79,0),(595,100)),
('U4','SN74LVC08ADR','Package_SO:SOIC-14_3.9x8.7mm_P1.27mm',['L_IN1','FPGA_PWM_L','DRV_AIN1','L_IN2','FPGA_PWM_L','DRV_AIN2','BASE_GND','DRV_BIN1','R_IN3','FPGA_PWM_R','DRV_BIN2','R_IN4','FPGA_PWM_R','BASE_3V3'],(137,45,0),(770,100)),
('U1','ISO7721DR','Package_SO:SOIC-8_3.9x4.9mm_P1.27mm',['HOST_3V3','H_RX','H_TX','H_GND','BASE_GND','RP_UART_RX','RP_UART_TX','BASE_3V3'],(75,15,0),(945,100)),
('C1','100nF 16V X7R',C,['HOST_3V3','H_GND'],(69,15,-90),(0,0)),
('C2','100nF 16V X7R',C,['BASE_3V3','BASE_GND'],(81,15,-90),(0,0)),
('J3','HC_SR04_VCC_TRIG_ECHO_GND',SENSOR_FP(4),['BASE_5V','SENSOR_TRIG','US_ECHO_5V','BASE_GND'],(84,91,0),(0,0)),
('R1','1k 1%',R,['US_TRIG','SENSOR_TRIG'],(86,76,0),(0,0)),
('R2','2.2k 1%',R,['US_ECHO_5V','ECHO_DIV'],(91,81,0),(0,0)),
('R3','3.3k 1%',R,['ECHO_DIV','BASE_GND'],(85,81,0),(0,0)),
('U2','SN74LVC1G17DBVR','Package_TO_SOT_SMD:SOT-23-5',[None,'ECHO_DIV','BASE_GND','US_ECHO_3V','BASE_3V3'],(91,75,0),(0,0)),
('C3','100nF 16V X7R',C,['BASE_3V3','BASE_GND'],(95,75,90),(0,0)),
('R4','10k 1%',R,['ESTOP_N','BASE_GND'],(95,14,90),(0,0)),
('R5','10k 1%',R,['FPGA_PWM_L','BASE_GND'],(136,55,0),(0,0)),
('R6','10k 1%',R,['FPGA_PWM_R','BASE_GND'],(136,58,0),(0,0)),
('R7','0.20R 1W CSRT1206FTR200','Resistor_SMD:R_1206_3216Metric',['SENSE_L','BASE_GND'],(115.5,75.5,180),(0,0)),
('R8','0.20R 1W CSRT1206FTR200','Resistor_SMD:R_1206_3216Metric',['SENSE_R','BASE_GND'],(115.5,82.5,180),(0,0)),
('R9','10k 1%',R,['DRV_FAULT_N','BASE_3V3'],(133,64,0),(0,0)),
('R10','10k 1%',R,['L_IN1','BASE_GND'],(88,32,0),(0,0)),
('R11','10k 1%',R,['L_IN2','BASE_GND'],(88,35,0),(0,0)),
('R12','10k 1%',R,['R_IN3','BASE_GND'],(88,38,0),(0,0)),
('R13','10k 1%',R,['R_IN4','BASE_GND'],(88,41,0),(0,0)),
('C4','100nF 16V X7R',C,['BASE_3V3','BASE_GND'],(141,38,0),(0,0)),
('C5','10uF 16V X7R','Capacitor_SMD:C_1206_3216Metric',['MOTOR_6V','BASE_GND'],(129.8,79.325,0),(0,0)),
('C6','10nF 25V X7R',C,['DRV_VCP','MOTOR_6V'],(128,82.4,-90),(0,0)),
('C7','2.2uF 16V X7R',C,['DRV_VINT','BASE_GND'],(128.85,76.1,0),(0,0)),
('C8','470uF 16V','Capacitor_THT:CP_Radial_D8.0mm_P3.50mm',['MOTOR_6V','BASE_GND'],(126,89,0),(0,0)),
('D1','SMBJ6.0A','Diode_SMD:D_SMB',['MOTOR_6V','BASE_GND'],(138,90,0),(0,0)),
('J5','ESTOP_LOGIC_NC',xh(2),['BASE_3V3','ESTOP_N'],(86,8,0),(0,0)),
('J6','BASE_SENSOR_5V_IN',xh(2),['BASE_5V','BASE_GND'],(110,91,0),(0,0)),
('J7','6V_AFTER_FUSE_AND_STOP_RELAY',POWER_FP,['MOTOR_6V','BASE_GND'],(149,86,0),(0,0)),
('J8','LEFT_MOTOR',POWER_FP,['MOTOR_L_P','MOTOR_L_N'],(151,59,90),(0,0)),
('J9','RIGHT_MOTOR',POWER_FP,['MOTOR_R_P','MOTOR_R_N'],(151,43,90),(0,0)),
('J10','ENCODER_LEFT_3V3',SENSOR_FP(4),['BASE_GND','BASE_3V3','ENC_L_A','ENC_L_B'],(128,8,0),(0,0)),
('J11','ENCODER_RIGHT_3V3',SENSOR_FP(4),['BASE_GND','BASE_3V3','ENC_R_A','ENC_R_B'],(143,13,0),(0,0)),
('J12','ALTERNATE_HOST_UART',xh(4),['HOST_3V3','H_GND','H_TX','H_RX'],(18,11,0),(0,0)),
('J13','IMU_3V3_I2C_INT',SENSOR_FP(5),['BASE_GND','BASE_3V3','IMU_SDA','IMU_SCL','IMU_INT'],(135,22,0),(0,0)),
('R14','4.7k 1%',R,['IMU_SDA','BASE_3V3'],(133,30,0),(0,0)),
('R15','4.7k 1%',R,['IMU_SCL','BASE_3V3'],(140,30,0),(0,0)),
('U5','SN74LVC125ADR','Package_SO:SOIC-14_3.9x8.7mm_P1.27mm',['BASE_GND','ESTOP_N','ESTOP_RP_DRIVE','BASE_GND','ESTOP_N','ESTOP_FPGA_DRIVE','BASE_GND','FAULT_RP_DRIVE','DRV_FAULT_N','BASE_GND','FAULT_FPGA_DRIVE','DRV_FAULT_N','BASE_GND','BASE_3V3'],(87,56,0),(0,0)),
('C9','100nF 16V X7R',C,['BASE_3V3','BASE_GND'],(94,56,0),(0,0)),
('R16','1k 1%',R,['ESTOP_RP_DRIVE','ESTOP_RP'],(94,47,0),(0,0)),
('R17','1k 1%',R,['ESTOP_FPGA_DRIVE','ESTOP_FPGA'],(94,51,0),(0,0)),
('R18','1k 1%',R,['FAULT_RP_DRIVE','FAULT_RP_N'],(94,61,0),(0,0)),
('R19','1k 1%',R,['FAULT_FPGA_DRIVE','FAULT_FPGA_N'],(94,65,0),(0,0)),
]
# Copper-only service pads: no fitted part, paste or added load on the signal.
TEST_POINTS=[
    ('TP1','HOST_3V3',63,11), ('TP2','H_GND',63,16),
    ('TP3','BASE_3V3',82,22), ('TP4','BASE_5V',101,91),
    ('TP5','MOTOR_6V',144,76), ('TP6','BASE_GND',109,81),
    ('TP7','ESTOP_N',82,28), ('TP8','DRV_FAULT_N',109,86),
    ('TP9','SENSE_L',116.9625,71.5), ('TP10','SENSE_R',116.9625,86.5),
]
PARTS += [(ref,net,'TestPoint:TestPoint_Pad_D1.5mm',[net],(x,y,0),(0,0)) for ref,net,x,y in TEST_POINTS]
# Distribute the remaining small blocks on one legible A0 electrical sheet.
PARTS=[p[:-1]+((70+(i-6)%6*175,225+(i-6)//6*75),) if i>=6 else p for i,p in enumerate(PARTS)]
MOTOR_NETS={'MOTOR_6V','MOTOR_L_P','MOTOR_L_N','MOTOR_R_P','MOTOR_R_N','SENSE_L','SENSE_R'}
BOARD_W,BOARD_H=160,100
PI_HOLES=[(3.5,23.5),(61.5,23.5),(3.5,72.5),(61.5,72.5)]
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

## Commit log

2026-09-09 feat: add modular rover hardware review design
    [assembly-bom.csv, axiom_rover_assembly.step, base_chassis.stl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]
2026-09-09 feat: add interactive rover and populated PCB viewer
    [carrier-populated.step]
2026-09-09 fix(hardware): correct Pi mounting datum and document carrier gaps
    [Shrike-lite.kicad_pcb, Shrike-lite.step, axiom_rover_assembly.step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]
2026-09-09 Add Rev B Pi 5 and Shrike rover carrier and enclosure
    [Pi5_Socket_2x20.step, SSW-119-01-G-S.step, assembly-bom.csv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]
2026-09-09 test: add independent rover bench fixture
    [synthetic-capture.csv]
2026-09-09 feat(viewer): deploy lossless static CAD viewer to Vercel
2026-09-09 docs: document Git LFS checkout and migrated commit IDs
    [lfs-commit-map.csv]
2026-09-27 feat(pcb): improve Rev B.1 reliability and serviceability
    [carrier-B_Cu.gbl, carrier-B_Mask.gbs, carrier-B_Silkscreen.gbo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]
